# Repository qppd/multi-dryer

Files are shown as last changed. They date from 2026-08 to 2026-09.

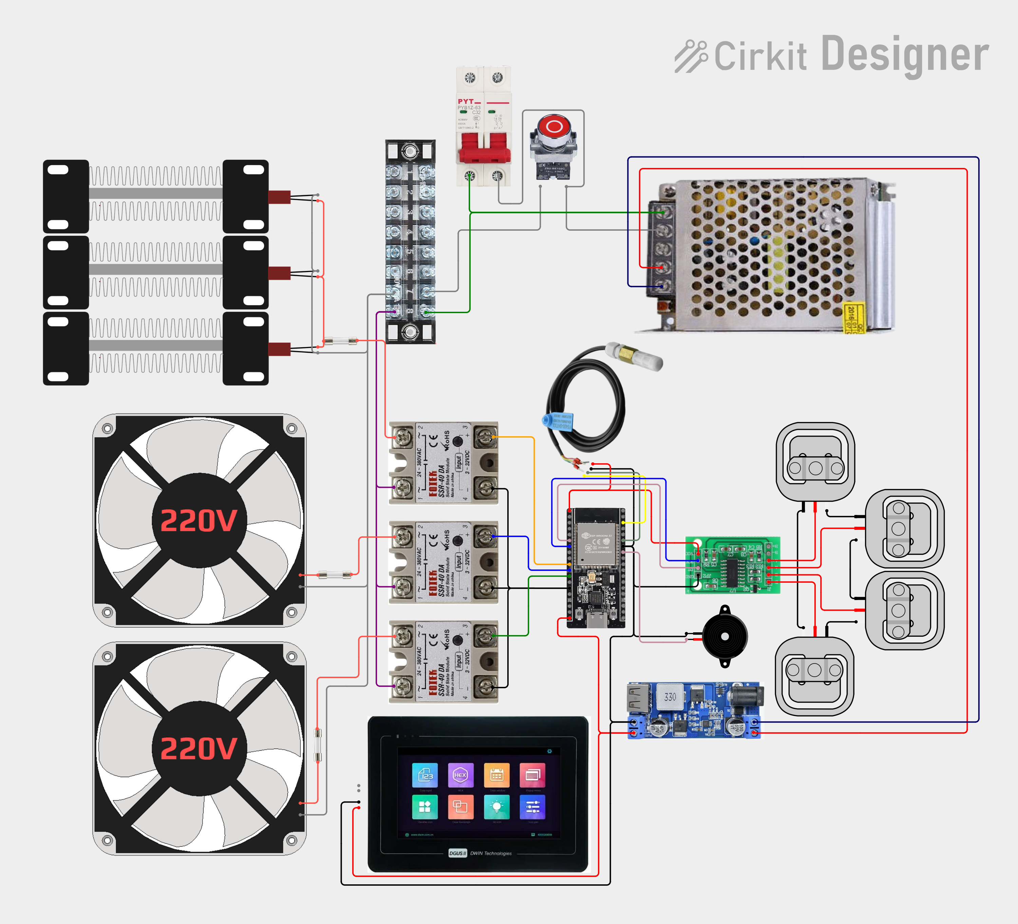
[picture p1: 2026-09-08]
docs/schematic/circuit_image.png

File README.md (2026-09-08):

# Multi Dryer







Smart food dehydration system built on a pair of ESP32 boards: a **controller** that runs the drying process (PTC heater, fans, load cell, temperature sensing) and a **touchscreen HMI** that provides the user interface. The two halves communicate **wirelessly over ESP-NOW** — no wiring between boards.

## Features

- **PID temperature control** — PTC heater regulated from SHT31 feedback (PD tuning, 0–5000 output, heat-vs-vent SSR strategy). Safety guard: the heater is forced OFF and the unit vents if the sensor feedback is lost.
- **Water-loss tracking** — load cell (HX711) measures the product weight; water loss is computed as % of the initial weight, with a configurable auto-complete target.
- **Drying state machine** — `IDLE → DRYING ⇄ PAUSED → COMPLETE`, with pause-aware runtime accounting and a rate-based *estimated drying time* (EDT).
- **Session persistence (NVS)** — interrupted drying sessions survive reboot/power-cycle: initial weight + HX711 zero reference, elapsed runtime, and targets are restored automatically (DRYING re-enables the PID). The last setpoint and water-loss target persist even when idle.
- **Full HMI control** — LVGL v8 touchscreen UI: dashboard, control, manual operation, analytics, diagnostics screens + completion alerts. Start / stop / pause / resume, **user-managed drying presets** (name + temperature + water-loss target, add/delete, saved in HMI NVS), live weight, water loss, runtime and EDT.
- **Manual overrides** — heater / inlet fan / exhaust toggles; any manual command ends an active session first so manual and automatic control never fight.
- **Boot- and WiFi-safe pin map** — no strapping, flash, or ADC2 pins used; all SSR outputs forced OFF at power-on (fail-safe).

## Repository Structure

```
multi-dryer/
├── src/
│   ├── MultiDryerController/   # ESP32 38-pin controller firmware (Arduino .ino + headers)
│   │   ├── MultiDryerController.ino   # entry point: sensors → PID → state machine → ESP-NOW
│   │   ├── PINS_CONFIG.h              # centralized, boot/WiFi-safe pin assignments
│   │   ├── SHT31_CONFIG.h             # SHT31 temp/humidity driver (I2C, non-blocking, CRC-8)
│   │   ├── LOADCELL_CONFIG.h          # HX711 load cell driver (kg, TARE/CALIBRATE, NVS factor)
│   │   ├── PID_CONFIG.h               # PID temperature control (PID_v1) + SHT31 vent guard
│   │   ├── DRYER_STATE.h              # state machine, water-loss math, NVS session persistence
│   │   ├── espnow_link.h              # ESP-NOW transport (1 Hz status, command ring buffer)
│   │   └── espnow_protocol.h          # shared packet protocol (byte-identical in both halves)
│   └── MultiDryerHMI/          # ESP32-S3 touchscreen HMI firmware (LVGL v8)
│       ├── MultiDryerHMI.ino          # entry point
│       ├── *_screen.cpp/.h            # boot, dashboard, control, manual operation,
│       │                              # analytics, diagnostics + alert popup
│       ├── serial_protocol.cpp/.h     # ESP-NOW transport to the controller
│       ├── dryer_data.h               # data model bridged from status packets
│       ├── lvgl_v8_port.* / ui_theme.h / ui_styles.* / screen_manager.*
│       ├── ui_optimistic_state.*      # instant UI feedback, corrected by 1 Hz status
│       └── esp_panel_board_custom_conf.h  # Waveshare Touch-LCD-7 board config (verify!)
└── docs/
    ├── README.md                      # documentation index & roadmap
    ├── api/espnow-protocol.md         # ESP-NOW protocol/API reference
    ├── stacks/tech-stack.md           # hardware + firmware + library stack
    ├── guides/bring-up-checklist.md   # ordered boot/hardware verification
    ├── guides/calibration-guide.md    # TARE + CALIBRATE:<kg>, NVS persistence
    ├── guides/troubleshooting.md      # pairing, vent guard, NVS issues
    ├── guides/bom.md                  # parts list with specs & quantities
    ├── guides/test-plan.md            # unit tests + HMI screen checks
    ├── schematic/hardware-wiring.md   # written pin-by-pin wiring plan
    ├── schematic/wiring-diagram.md    # Fritzing schematic (primary) + Cirkit Designer link
    ├── schematic/multidryer.fzz       # editable Fritzing schematic source (3-SSR build)
    ├── schematic/multidryer_schematic.png  # exported schematic view (PNG)
    └── diagrams/                      # block diagram + flow charts (Mermaid)
```

## Documentation

- [docs/README.md](docs/README.md) — index & required-docs roadmap
- [ESP-NOW protocol / API](docs/api/espnow-protocol.md) — packets, commands, states, pairing
- [Technology stack](docs/stacks/tech-stack.md) — hardware, firmware, libraries, tools
- [Wiring diagram & schematic](docs/schematic/wiring-diagram.md) — Fritzing schematic (primary) + interactive Cirkit Designer link
- [Hardware wiring plan](docs/schematic/hardware-wiring.md) — written pin-by-pin reference
- [Bring-up checklist](docs/guides/bring-up-checklist.md) — ordered boot/hardware verification
- [Calibration guide](docs/guides/calibration-guide.md) — TARE + CALIBRATE:<kg> procedure, NVS persistence
- [Troubleshooting guide](docs/guides/troubleshooting.md) — pairing, no-status-packet, sensor-fail vent behavior
- [BOM / procurement](docs/guides/bom.md) — full parts list with specs, quantities, and sourcing notes
- [Test plan](docs/guides/test-plan.md) — unit tests for protocol/state machine + HMI screen checks
- [System architecture](docs/system-architecture.md) — modules, data flow, design decisions
- [Block diagram](docs/diagrams/block-diagram.md) / [Flow charts](docs/diagrams/flow-chart.md) — Mermaid diagrams
- [Safety & thermal design](docs/guides/safety-and-thermal.md) — SSR strategy, fuses, thermal cutoff, vent guard
- [HMI user guide](docs/guides/hmi-user-guide.md) — screens, buttons, first-use workflow
- [UI screenshots](docs/ui/) — PNG previews of the real HMI screens (rendered with a headless LVGL tool kept out of the repo)

## Hardware

| Part | Spec / Use |
|---|---|
| ESP32 38-pin DevKitC (WROOM-32) | Main controller |
| ESP32-S3 + 7″ touch display (Waveshare Touch-LCD-7) | HMI (LVGL UI) |
| PTC heater 1500 W + 220 V fans ×2 (inlet, exhaust) | Drying loads, switched by SSRs |
| SSR-40DA modules ×3, 40 A (3–32 VDC input) | AC load switching (firmware-enforced fail-safe) |
| HX711 + 4× 50 kg load cells (summed bridge) | Weight / water-loss measurement |
| SHT31 | Temperature & humidity (PID feedback) |
| 220 VAC → 12 V 5 A PSU + 12 V → 5 V 3 A buck | Low-voltage supply |

### Controller Pin Map (summary)

| Function | GPIO |
|---|---|
| SSR1 — PTC heater | 26 |
| SSR3 — inlet fan | 27 |
| SSR4 — exhaust fan | 13 |
| HX711 DOUT / SCK | 35 / 32 |
| SHT31 SDA / SCL | 21 / 22 |

Full wiring plan: [`docs/schematic/hardware-wiring.md`](docs/schematic/hardware-wiring.md), the Fritzing schematic ([`multidryer.fzz`](docs/schematic/multidryer.fzz) — view: [`multidryer_schematic.png`](docs/schematic/multidryer_schematic.png)), and the interactive [Cirkit Designer schematic](https://app.cirkitdesigner.com/project/9d03db5a-37c8-4f46-ac3f-7d5821ce26ce).

## Getting Started

### Prerequisites

**Controller** (`src/MultiDryerController`)
- Arduino IDE or PlatformIO with **ESP32 Arduino core**
- Libraries: [`br3ttb/PID_v1`](https://github.com/br3ttb/Arduino-PID-Library), [`bogde/HX711`](https://github.com/bogde/HX711) (`Preferences` is built-in)

**HMI** (`src/MultiDryerHMI`)
- **LVGL 8.x** (enable fonts *Montserrat 14/16/20/24/30/36/48* and widgets *meter/chart/bar/slider/switch/tabview/checkbox/spinner/keyboard/textarea* in `lv_conf.h`)
- **ESP32_Display_Panel** library (`esp_display_panel.hpp`)
- ⚠️ `esp_panel_board_custom_conf.h` is configured for the **Waveshare ESP32-S3-Touch-LCD-7** — verify it matches your display/touch hardware, or init will fail silently.

### Flashing

1. Open the sketch folders (`src/MultiDryerController` / `src/MultiDryerHMI`) in the Arduino IDE, select the correct board, and upload.
2. **Pair the boards** (one-time, both default to channel 1):
   1. Boot the controller → note its MAC from the serial monitor.
   2. Paste it into `CONTROLLER_PEER_MAC` in `src/MultiDryerHMI/serial_protocol.cpp`.
   3. Boot the HMI → note its MAC.
   4. Paste it into `HMI_PEER_MAC` in `src/MultiDryerController/espnow_link.h`, re-flash the controller.
3. Open the serial monitors — status packets should flow at 1 Hz once paired.

## How It Works

1. The **controller** samples the SHT31 and load cell, runs PID temperature control on the PTC heater, and tracks the drying state machine with water-loss math.
2. Every second it broadcasts an **ESP-NOW status packet** (state, temp/humidity, weight, water loss, setpoint, PID output, runtime, EDT) to the HMI.
3. The **HMI** renders the dashboard and relays user commands (start/stop/pause/resume, setpoint, water-loss target, manual overrides, tare/calibrate) back over ESP-NOW. Commands are handled through an 8-slot ring buffer, so bursts are never dropped.
4. The drying session auto-completes when the water-loss target is reached — and survives reboots via NVS.

> The shared protocol (`espnow_protocol.h`) is **byte-identical** in both firmware folders — keep the two copies in sync when changing it.

## Author

**Sajed Lopez Mendoza** — *Building intelligent solutions* 🚀

- GitHub: [@qppd](https://github.com/qppd)
- LinkedIn: [sajed-mendoza](https://www.linkedin.com/in/sajed-mendoza)

## License

Distributed under the [MIT License](LICENSE).

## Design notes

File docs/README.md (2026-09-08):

# Multi Dryer — Documentation

Central index of all project documentation.

## Existing Docs

| Doc | Path | Status |
|---|---|---|
| Wiring diagram & schematic | [`schematic/wiring-diagram.md`](schematic/wiring-diagram.md) | ✅ Fritzing schematic current (3-SSR) — Cirkit link stale (old 4-SSR) |
| Hardware wiring plan (written) | [`schematic/hardware-wiring.md`](schematic/hardware-wiring.md) | ✅ complete |
| ESP-NOW protocol / API | [`api/espnow-protocol.md`](api/espnow-protocol.md) | ✅ complete |
| Technology stack | [`stacks/tech-stack.md`](stacks/tech-stack.md) | ✅ complete |
| Bring-up / boot checklist | [`guides/bring-up-checklist.md`](guides/bring-up-checklist.md) | ✅ complete |
| Calibration guide | [`guides/calibration-guide.md`](guides/calibration-guide.md) | ✅ complete |
| Troubleshooting guide | [`guides/troubleshooting.md`](guides/troubleshooting.md) | ✅ complete |
| System architecture | [`system-architecture.md`](system-architecture.md) | ✅ complete |
| Block diagram | [`diagrams/block-diagram.md`](diagrams/block-diagram.md) | ✅ complete |
| Flow charts | [`diagrams/flow-chart.md`](diagrams/flow-chart.md) | ✅ complete |
| Safety & thermal design | [`guides/safety-and-thermal.md`](guides/safety-and-thermal.md) | ✅ complete |
| HMI user guide | [`guides/hmi-user-guide.md`](guides/hmi-user-guide.md) | ✅ complete |

> Written pin-by-pin plan, planning notes, and reference projects live in
> `references/` (local, git-ignored) — notably
> `references/plans/hardware-wiring.md` and `references/plans/multi-dryer-planning.md`.

## Required Docs — Roadmap

Docs that should exist before / during hardware bring-up, in priority order:

| # | Doc | Why it's required | Status |
|---|---|---|---|
| 1 | **Hardware wiring plan (written)** | Pin-by-pin reference for assembly & debugging | ✅ [`schematic/hardware-wiring.md`](schematic/hardware-wiring.md) |
| 2 | **Bring-up / boot checklist** | Ordered tests (boot, fail-safe, flash, WiFi, load cell, outputs, thermal) | ✅ [`guides/bring-up-checklist.md`](guides/bring-up-checklist.md) |
| 3 | **Calibration guide** | TARE + two-point `CALIBRATE:<kg>` procedure and how the factor/session offset persist in NVS | ✅ [`guides/calibration-guide.md`](guides/calibration-guide.md) |
| 4 | **Architecture overview** | Module diagram & data flow (sensors → PID → state machine → ESP-NOW → HMI) for onboarding | ✅ [`system-architecture.md`](system-architecture.md) + [`diagrams/`](diagrams/) |
| 5 | **HMI user guide** | What each screen does, button semantics (start/pause/resume/stop, presets, manual mode) | ✅ [`guides/hmi-user-guide.md`](guides/hmi-user-guide.md) |
| 6 | **Troubleshooting guide** | MAC pairing, no-status-packet, sensor-fail vent behavior, NVS session resurrection | ✅ [`guides/troubleshooting.md`](guides/troubleshooting.md) |
| 7 | **Safety & thermal design** | SSR strategy, fuses, thermal cutoff, SHT31 vent guard, live-wiring rules | ✅ [`guides/safety-and-thermal.md`](guides/safety-and-thermal.md) |
| 8 | **BOM / procurement** | Parts list with specs & quantities for ordering | ✅ [`guides/bom.md`](guides/bom.md) |
| 9 | **Test plan** | Unit/bench tests for the state machine & protocol helpers, HMI screen checks | ✅ [`guides/test-plan.md`](guides/test-plan.md) |

## Conventions

- Keep protocol docs in sync with `espnow_protocol.h` (the header is the source of truth).
- Keep the shared header **byte-identical** in both firmware folders.
- Diagrams go in `docs/diagrams/`, schematics in `docs/schematic/`.

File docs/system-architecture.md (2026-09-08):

# System Architecture

High-level architecture of the Multi Dryer: two ESP32 boards, one shared
wireless protocol, and the module/data-flow design of each firmware.

> Diagrams: [`diagrams/block-diagram.md`](diagrams/block-diagram.md) ·
> [`diagrams/flow-chart.md`](diagrams/flow-chart.md) ·
> Protocol: [`api/espnow-protocol.md`](api/espnow-protocol.md) ·
> Stack: [`stacks/tech-stack.md`](stacks/tech-stack.md)

---

## 1. Overview

The system is a **two-board distributed design** with a strict separation of
concerns:

```
┌──────────────────────────────┐        ESP-NOW (wireless)        ┌──────────────────────────────┐
│        CONTROLLER            │ ◄══════════════════════════════► │             HMI              │
│   ESP32 38-pin (WROOM-32)    │    status 1 Hz / commands        │   ESP32-S3 + 7" touch LCD   │
│                              │                                  │                              │
│  sensing · control · safety  │                                  │  display · input · state     │
└──────────────────────────────┘                                  └──────────────────────────────┘
```

- The **controller** is the brain: it owns the sensors, the PID, the drying
  state machine, and the safety rules. It never needs the HMI to operate safely.
- The **HMI** is the face: LVGL touchscreen UI, optimistic button feedback, and
  display of controller data. It never makes control decisions.
- The only link is **ESP-NOW** — no UART, no I2C between boards. Each board's
  serial (UART0) is local flashing/debug only.

**Why two boards?** The 38-pin ESP32 runs the real-time control loop with clean
GPIOs for the SSRs and sensors; the ESP32-S3 runs the display without sharing
the controller's I/O. ESP-NOW keeps them physically independent (no wiring, no
ground loops in the mains enclosure).

---

## 2. Controller Architecture

Modules in `src/MultiDryerController/`, roughly in init order:

| Module | Responsibility |
|---|---|
| `MultiDryerController.ino` | Entry point: init sequence (pins → load cell → SHT31 → PID → drying → ESP-NOW) and the main loop |
| `PINS_CONFIG.h` | Boot/WiFi-safe pin assignments (single source of truth) |
| `SHT31_CONFIG.h` | Non-blocking SHT31 driver (I2C, CRC-8) → `getTemperature()` / `getHumidity()` |
| `LOADCELL_CONFIG.h` | HX711 driver: kg reads, TARE/CALIBRATE, factor in NVS |
| `PID_CONFIG.h` | PID_v1 temperature control + **vent safety guard** |
| `DRYER_STATE.h` | State machine, water-loss math, runtime/EDT, NVS session & config persistence |
| `espnow_link.h` | ESP-NOW: 1 Hz status broadcast, 8-slot command ring buffer |
| `espnow_protocol.h` | Shared packet protocol (byte-identical copy) |

### 2.1 Data flow (per loop iteration)

```
SHT31 ──► temperature/humidity ─┐
                                ├─► PID (PID_CONFIG) ─► SSRs (heat/vent)
HX711 ──► weight (1 Hz cache) ─┤        ▲ setpoint
                                └─► DRYER_STATE (state machine, water loss)
                                        │
espnow_link ◄── status packet (1 Hz) ───┘   commands ──► state machine / PID / manual
```

### 2.2 Safety architecture

1. **Boot fail-safe** — firmware forces all SSR pins LOW as the first step
   of `setup()`: nothing energizes during boot.
2. **Sensor-fail vent guard** — if `sht31OK` is false, `pidCOMPUTE()` forces
   heater + inlet fan OFF and vents (exhaust fan on): a dead sensor can
   never cause full-power heating.
3. **State-machine/manual arbitration** — any manual command ends an active
   session first, so PID and manual control never fight.
4. **TARE/CALIBRATE gate** — calibration is blocked unless IDLE, so a boot-time
   TARE can't destroy a restored session's zero reference.
5. **Hardware thermal cutoff** — thermal fuse/limit switch in series with the
   PTC heater branch (outside firmware).

---

## 3. HMI Architecture

Modules in `src/MultiDryerHMI/`:

| Module | Responsibility |
|---|---|
| `MultiDryerHMI.ino` | Entry point |
| `serial_protocol.*` | ESP-NOW transport: senders + `applyStatusPacket` (packet → `dryerData`) |
| `dryer_data.h` | Data model — the single source the screens read |
| `screen_manager.*` | Screen navigation |
| `boot_screen` / `dashboard` / `control` / `manual_operation` / `analytics` / `diagnostics` / `alert_popup` | LVGL screens |
| `ui_optimistic_state.*` | Instant UI feedback on button press, corrected by the next 1 Hz status |
| `lvgl_v8_port.*`, `ui_theme.h`, `ui_styles.*` | LVGL port, theme, styles |
| `esp_panel_board_custom_conf.h` | Display/touch board config (Waveshare-7″) |

### 3.1 UI data flow

```
ESP-NOW status ──► applyStatusPacket ──► dryerData ──► screens (2 s UI refresh)
ESP-NOW command ◄── button callbacks ◄── optimistic state ── touch input
```

---

## 4. Communication Architecture

- **Transport:** ESP-NOW over Wi-Fi STA, channel 1, no network connection.
- **Packets:** packed binary structs + XOR checksum (see `espnow_protocol.h`).
  - `EspNowStatusPacket` (38 B) — controller → HMI, 1 Hz.
  - `EspNowCmdPacket` (7 B) — HMI → controller, on demand.
- **Reliability:** status is periodic (a missed packet self-heals); commands are
  queued in an 8-slot ring buffer so bursts are never dropped during the
  ~300 ms HX711 read window. ESP-NOW ACK tracks `hmiReachable`.
- **Authoritative data:** runtime, EDT, water loss, and weight always come from
  the controller — the HMI never recomputes them.

---

## 5. Persistence Architecture (NVS)

| Namespace | Keys | Contents | Written by |
|---|---|---|---|
| `loadcell` | `factor` | Calibration factor (counts/kg) | `CALIBRATE:<kg>` |
| `drying` | `magic`, `state`, `initW`, `runMs`, `wlTgt`, `setpt`, `hxoff` | Active session: state, initial weight, elapsed runtime, water-loss target, setpoint, **HX711 raw offset** | session transitions + every 30 s while drying |
| `drying` | `magic`, `wlTgt`, `setpt` | Idle config (survives reboot with no session) | `SET_TEMPERATURE` / `SET_WATER_LOSS` |

Restore rules: valid `magic` + non-IDLE `state` → resume session (re-apply
offset, PID back on if DRYING). Config keys restore in every boot. Session
completion/stop clears the state marker only — config keys are preserved.

---

## 6. Key Design Decisions

| Decision | Rationale |
|---|---|
| ESP-NOW instead of wires | No inter-board wiring, no ground loops; same transport as the HMI reference baseline |
| Controller owns all safety | The dryer remains safe even if the HMI is dead or absent |
| 1 Hz weight cache in the state machine | Single read source → status packet and water-loss math always agree |
| NVS offset saved with the session | Survives full power cycles where HX711 offset drifts — no re-tare |
| Optimistic HMI UI | Feels instant; the 1 Hz status packet is the correction source |
| Boot-safe pin map | No strapping/flash/ADC2 pins → flashing and WiFi always work with peripherals attached |

## 7. References

- Wiring: [`schematic/hardware-wiring.md`](schematic/hardware-wiring.md)
- Protocol: [`api/espnow-protocol.md`](api/espnow-protocol.md)
- Stack: [`stacks/tech-stack.md`](stacks/tech-stack.md)
- Bring-up: [`guides/bring-up-checklist.md`](guides/bring-up-checklist.md)
- Troubleshooting: [`guides/troubleshooting.md`](guides/troubleshooting.md)

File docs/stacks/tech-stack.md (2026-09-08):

# Technology Stack

Everything used to build the Multi Dryer system — hardware, firmware, libraries,
and tooling.

---

## 1. Hardware Stack

| Layer | Item | Role |
|---|---|---|
| Controller MCU | **ESP32 38-pin DevKitC** (WROOM-32 module) | Runs the drying process: sensors, PID, state machine, ESP-NOW |
| HMI MCU | **ESP32-S3** (Waveshare ESP32-S3-Touch-LCD-7) | 800×480 RGB LCD + GT911 capacitive touch, runs the LVGL UI |
| Temperature/humidity | **SHT31** (I2C, addr 0x44) | Chamber feedback for PID + humidity reporting |
| Weight | **HX711** 24-bit ADC + 4× 50 kg load cells (summed full-bridge, 200 kg) | Product weight → water-loss % |
| Heating | **PTC heater** (1500 W) | Drying heat, switched by SSR1 |
| Airflow | Inlet fan + exhaust fan (220 V AC) | Circulation & moisture venting, SSRs 3–4 |
| Power switching | **3× SSR-40DA (40 A)** (3–32 VDC input / 220 VAC output) | Opto-isolated mains switching; firmware-enforced fail-safe OFF at boot |
| Power | 220 VAC → 12 V 5 A PSU + 12 V → 5 V 3 A buck converter | 5 V rail feeds ESP32; onboard regulator makes 3.3 V |
| Protection | Fuses per AC branch + thermal cutoff on heater branch | Safety |

Pin allocation: `src/MultiDryerController/PINS_CONFIG.h` · wiring plan:
`docs/schematic/wiring-diagram.md`

---

## 2. Firmware Stack

### Controller — `src/MultiDryerController` (Arduino sketch + headers)

| Module | Responsibility |
|---|---|
| `MultiDryerController.ino` | Entry point: init order (pins → load cell → SHT31 → PID → drying → ESP-NOW), main loop |
| `PINS_CONFIG.h` | Boot/WiFi-safe pin assignments |
| `SHT31_CONFIG.h` | Non-blocking SHT31 driver, hardware I2C, CRC-8 |
| `LOADCELL_CONFIG.h` | HX711 driver: kg readings, TARE/CALIBRATE, calibration factor in NVS |
| `PID_CONFIG.h` | PID temperature control (PID_v1) + SHT31 vent safety guard |
| `DRYER_STATE.h` | State machine, water-loss math, runtime/EDT, NVS session + config persistence |
| `espnow_link.h` | ESP-NOW transport: 1 Hz status, 8-slot command ring buffer |
| `espnow_protocol.h` | Shared protocol (byte-identical copy) |

### HMI — `src/MultiDryerHMI` (Arduino sketch, LVGL v8)

| Module | Responsibility |
|---|---|
| `MultiDryerHMI.ino` | Entry point |
| `boot_screen` / `dashboard_screen` / `control_screen` / `manual_operation_screen` / `analytics_screen` / `diagnostics_screen` / `alert_popup` | UI screens |
| `serial_protocol.*` | ESP-NOW transport to the controller |
| `dryer_data.h` | Data model bridged from status packets |
| `ui_optimistic_state.*` | Instant button feedback, corrected by 1 Hz status |
| `lvgl_v8_port.*`, `ui_theme.h`, `ui_styles.*`, `screen_manager.*` | LVGL port, theme, screen navigation |
| `esp_panel_board_custom_conf.h` | Board config — **Waveshare-7″-specific, verify against real hardware** |

---

## 3. Libraries

| Library | Used by | Version / notes |
|---|---|---|
| **ESP32 Arduino core** | both | `WiFi`, `Preferences`, `Wire` (built-in) |
| **PID_v1** (`br3ttb/Arduino-PID-Library`) | controller | PD tuning: KP 4.0, KI 0.0, KD 22.0 |
| **HX711** (`bogde/HX711`) | controller | Reads + tare + offset management |
| **LVGL 8.x** | HMI | Fonts Montserrat 14/16/20/24/30/36/48; widgets meter/chart/bar/slider/switch/tabview/checkbox/spinner |
| **ESP32_Display_Panel** (`esp_display_panel.hpp`) | HMI | RGB LCD + GT911 touch init (Waveshare board config) |

---

## 4. Communication

- **Transport:** ESP-NOW (Wi-Fi STA mode, channel 1) — wireless, no wiring between boards.
- **Protocol:** packed binary structs + XOR checksum, defined in `espnow_protocol.h`
  (byte-identical on both sides). Full reference: `docs/api/espnow-protocol.md`.
- **Cadence:** status 1 Hz; commands on-demand with an 8-slot receive queue.
- **Persistence:** NVS (`Preferences`, namespace `drying`) for calibration factor,
  session state, and last setpoint/water-loss target.

---

## 5. Tooling

| Tool | Use |
|---|---|
| Arduino IDE (or PlatformIO) | Build & flash both sketches |
| esptool / Arduino uploader | Flashing via UART0 (GPIO 1/3) |
| Serial monitor | MAC pairing, debug prints |
| **Fritzing** (0.9.3b) | Canonical editable schematic — `docs/schematic/multidryer.fzz` (see [`wiring-diagram.md`](../schematic/wiring-diagram.md)) |
| Cirkit Designer | Legacy interactive wiring schematic (link in `docs/schematic/wiring-diagram.md`) |
| GitHub (qppd/multi-dryer) | Version control, docs, issues |
| PID_v1 / HX711 / LVGL docs | Library API references |

---

## 6. Design Principles (why the stack is safe)

1. **Boot-safe pins** — no strapping (0/2/4/5/12/15), flash (6–11), or boot-PWM (14) pins.
2. **WiFi-safe pins** — no analog reads on ADC2 (unusable with WiFi active); HX711 path is fully digital.
3. **Fail-safe outputs** — firmware forces all SSR pins LOW first thing in `setup()`.
4. **Sensor-fail safety** — SHT31 loss forces the heater OFF and vents instead.
5. **Single transport** — ESP-NOW only between boards; UART0 is local debug only.

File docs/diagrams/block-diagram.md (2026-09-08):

# Block Diagram

System block diagram (Mermaid — renders on GitHub).

```mermaid
flowchart TB
    subgraph AC["220 VAC Mains"]
        M[AC-L / AC-N]
    end

    subgraph PWR["Power"]
        PSU["220 V → 12 V 5 A PSU"]
        BUCK["12 V → 5 V 3 A buck"]
        F1["Fuse 10A"] & F2["Fuse 2A"] & F3["Fuse 2A"]
        TCO["Thermal cutoff<br/>(heater branch)"]
    end

    subgraph CTRL["CONTROLLER — ESP32 38-pin (WROOM-32)"]
        direction TB
        ESP["ESP32 SoC"]
        subgraph MOD["Firmware modules"]
            SHT["SHT31_CONFIG.h"]
            LC["LOADCELL_CONFIG.h"]
            PID["PID_CONFIG.h<br/>+ vent guard"]
            ST["DRYER_STATE.h<br/>state machine / NVS"]
            LNK["espnow_link.h"]
            SHARED["espnow_protocol.h<br/>(shared, byte-identical)"]
        end
    end

    subgraph SENS["Sensors"]
        S31["SHT31<br/>temp/humidity<br/>(I2C 21/22)"]
        HX["HX711<br/>(DOUT 35 / SCK 32)"]
        CELL["Load cells 4× 50 kg<br/>(summed bridge)"]
    end

    subgraph SSR["SSR Bank — 3× SSR-40DA 40 A (3–32 VDC in)"]
        R1["SSR1 — PTC heater<br/>(GPIO 26)"]
        R3["SSR3 — inlet fan<br/>(GPIO 27)"]
        R4["SSR4 — exhaust fan<br/>(GPIO 13)"]
    end

    subgraph LOADS["AC Loads"]
        HTR["PTC heater 1500 W"]
        IF["Inlet fan"]
        EF["Exhaust fan"]
    end

    subgraph HMI["HMI — ESP32-S3 + 7″ touch LCD"]
        HMI_ESP["ESP32-S3"]
        DSP["RGB LCD 800×480<br/>(ST7262)"]
        TCH["GT911 touch"]
        subgraph HMI_MOD["Firmware modules"]
            PROTO["serial_protocol.*<br/>(ESP-NOW)"]
            PRESETS["drying_presets.*<br/>(NVS presets)"]
            OPT["ui_optimistic_state.*<br/>(instant feedback)"]
            SM["screen_manager.*<br/>6 screens + alerts"]
        end
        LVGL["LVGL 8.x UI"]
    end

    M --> PSU --> BUCK --> ESP
    ESP --> S31 & HX
    CELL --> HX
    S31 -.->|I2C| SHT
    HX -.->|kg| LC
    M --> F1 --> TCO --> R1
    M --> F2 --> R3
    M --> F3 --> R4
    R1 --> HTR
    R3 --> IF
    R4 --> EF

    SHT --> PID
    LC --> ST
    PID --> ST
    ST --> LNK
    LNK -. "ESP-NOW 1 Hz status" .-> PROTO
    PROTO -. "commands" .-> LNK
    PRESETS --> LVGL
    OPT --> LVGL
    SM --> LVGL
    PROTO --> LVGL
    LVGL --> DSP
    TCH --> LVGL
    HMI_ESP --> DSP & TCH
```

## Legend

| Block | Notes |
|---|---|
| Mains | 220 VAC, fused per branch (10/2/2 A) |
| PSU | 220 V → 12 V 5 A PSU + 12 V → 5 V 3 A buck (5 V rail → ESP32; onboard regulator makes 3.3 V) |
| Thermal cutoff | Mandatory, in series with the PTC heater branch |
| SSR bank | 3× SSR-40DA 40 A (SSR1 heater, SSR3 inlet, SSR4 exhaust); opto-isolated 3–32 VDC input; firmware forces inputs LOW at boot |
| ESP-NOW | Wireless, channel 1, packed binary packets — `espnow_protocol.h` is byte-identical on both boards (see `api/espnow-protocol.md`) |
| Sensors | SHT31 on I2C; HX711 fully digital (no ADC2 dependence) |
| HMI | ESP32-S3 + 7″ RGB LCD (ST7262) + GT911 touch; LVGL 8.x; 6 screens (boot, dashboard, control, analytics, diagnostics, HOW TO USE); drying presets in NVS; optimistic button feedback; alerts |

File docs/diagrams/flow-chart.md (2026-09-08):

# Flow Charts

Control-flow diagrams (Mermaid — renders on GitHub).

---

## 1. Controller Boot Flow

```mermaid
flowchart TD
    A["Power on / reset"] --> B["setup()<br/>1. SSR pins forced LOW (fail-safe)"]
    B --> C["2. initLoadCell() — HX711<br/>restore calibration factor from NVS"]
    C --> D["3. initSHT31() — I2C<br/>temp/humidity, presence check"]
    D --> E["4. initPID() — MANUAL (off)"]
    E --> F["5. initDrying() — restore<br/>session + config from NVS"]
    F --> G["6. initEspNow() — pair peer<br/>+ register callbacks"]
    G --> H{"Saved session?"}
    H -->|"PAUSED"| I["Stay PAUSED — all outputs off"]
    H -->|"DRYING"| J["Resume DRYING — PID back on,<br/>HX711 offset re-applied"]
    H -->|"none / COMPLETE"| K["IDLE — config restored<br/>(setpoint + water-loss target)"]
    I --> L["loop()"]
    J --> L
    K --> L
```

---

## 2. Main Loop (every iteration)

```mermaid
flowchart TD
    A["loop()"] --> B["updateSHT31()<br/>non-blocking sensor read<br/>state machine"]
    B --> C["pidCOMPUTE()<br/>heat or vent — SHT31 vent guard<br/>(PID_v1 throttles to 2 s)"]
    C --> D["updateDrying()<br/>1 Hz tick — weight cache, water loss,<br/>EDT, auto-complete, session save"]
    D --> E["espnowUpdate()<br/>dequeue 1 cmd + 1 Hz status"]
    E --> F["5 s debug status print"]
    F --> A
```

---

## 3. Drying State Machine

```mermaid
stateDiagram-v2
    [*] --> IDLE: boot — no saved session
    [*] --> DRYING: boot — saved DRYING<br/>(PID back on)
    [*] --> PAUSED: boot — saved PAUSED<br/>(all outputs off)
    IDLE --> DRYING: START_DRYING<br/>(capture initial weight, PID on)
    DRYING --> PAUSED: PAUSE_DRYING<br/>(all SSRs off, session saved)
    PAUSED --> DRYING: RESUME_DRYING<br/>(PID back on)
    DRYING --> COMPLETE: water loss ≥ target<br/>(auto — all SSRs off, session cleared)
    COMPLETE --> IDLE: STOP_DRYING
    COMPLETE --> DRYING: START_DRYING<br/>(fresh session)
    PAUSED --> IDLE: STOP_DRYING
    DRYING --> IDLE: STOP_DRYING / manual override
    IDLE --> IDLE: manual HEATER/FAN/EXHAUST
```

> **Boot-resume:** `initDrying()` restores a saved session from NVS — a DRYING
> session re-enables the PID; a PAUSED session stays off. Completed sessions
> clear the NVS marker, so a finished cycle always boots to IDLE.

---

## 4. PID + Sensor-Fail Decision

```mermaid
flowchart TD
    A["pidCOMPUTE()"] --> B{"PID mode == AUTOMATIC?"}
    B -->|"NO (MANUAL)"| Z["Return — outputs untouched"]
    B -->|"YES"| C{"SHT31 valid?"}
    C -->|"NO"| V["VENT SAFETY:<br/>heater OFF, inlet OFF<br/>exhaust fan ON"]
    C -->|"YES"| D["pid.Compute()"]
    D --> E{"PID_OUTPUT > 0?"}
    E -->|"YES"| H["HEAT:<br/>SSR1 PTC + SSR3 inlet ON<br/>SSR4 OFF"]
    E -->|"NO"| V2["VENT:<br/>SSR1 + SSR3 OFF<br/>SSR4 exhaust fan ON"]
    V --> Z
    H --> Z
    V2 --> Z
```

---

## 5. ESP-NOW Command Path (HMI → Controller)

```mermaid
sequenceDiagram
    participant UI as LVGL screen (HMI)
    participant H as serial_protocol (HMI)
    participant C as espnow_link (Controller)
    participant S as State machine / PID

    UI->>H: button callback
    H->>H: optimistic UI state (instant)
    H->>C: EspNowCmdPacket (7 B)
    C->>C: validate + enqueue (8-slot ring)
    C->>C: dequeue 1 per loop
    C->>S: handleCmd()
    S-->>C: effect (start/pause/…)
    C-->>H: status packet (1 Hz, corrects UI)
```

---

> Related: [`../system-architecture.md`](../system-architecture.md) ·
> [`api/espnow-protocol.md`](../api/espnow-protocol.md) ·
> [`guides/bring-up-checklist.md`](../guides/bring-up-checklist.md)

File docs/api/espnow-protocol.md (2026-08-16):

# ESP-NOW Protocol Reference (Controller ⇄ HMI)

The two firmware halves communicate **exclusively over ESP-NOW** — a wireless,
low-latency link built into the ESP32. There is **no wired connection** (no UART,
no I2C) between the controller and the HMI.

- **Shared header:** `espnow_protocol.h` — **byte-identical** in
  `src/MultiDryerController/` and `src/MultiDryerHMI/`. Keep both copies in sync
  when changing the protocol.
- **Wi-Fi channel:** `ESPNOW_WIFI_CHANNEL` = 1 on both sides.
- **Mode:** both boards run `WiFi.mode(WIFI_STA)` (no network connection needed).

---

## 1. Packet Framing

Both packets are packed C structs (little-endian, ESP32 Xtensa — binary-compatible
between boards). Every packet ends with a **checksum**: the XOR of all preceding
bytes. A receiver drops any packet whose type or checksum doesn't validate.

```
| packetType | payload ... | checksum |
```

| Packet | Direction | Size | ID |
|---|---|---|---|
| `EspNowStatusPacket` | Controller → HMI | **38 bytes** | `0x01` |
| `EspNowCmdPacket` | HMI → Controller | **7 bytes** | `0x02` |

---

## 2. EspNowStatusPacket — Controller → HMI (38 bytes)

Broadcast at **1 Hz** while the controller is running, and on demand after
`CMD_STATUS_REQUEST` / `CMD_SENSOR_TEST`. This is the HMI's only source of truth
for the machine state.

| Field | Type | Bytes | Description |
|---|---|---|---|
| `packetType` | uint8_t | 1 | `ESPNOW_PKT_STATUS` (0x01) |
| `state` | uint8_t | 1 | `DSTATE_*` — see [§4](#4-dryer-states) |
| `flags` | uint8_t | 1 | `FLAG_*` bitmask — see [§5](#5-status-flags) |
| `temperature` | float | 4 | Chamber temperature, °C (SHT31) |
| `humidity` | float | 4 | Humidity, % (SHT31) |
| `weight` | float | 4 | Current product weight, kg (HX711, 1 Hz cache) |
| `waterLoss` | float | 4 | Water lost so far, % of initial weight |
| `setpoint` | float | 4 | Target temperature, °C |
| `waterLossTarget` | float | 4 | Auto-complete target, % (0 = disabled) |
| `pidOutput` | float | 4 | PID output, 0–5000 |
| `runtimeSeconds` | uint16_t | 2 | Drying runtime (pauses excluded), s — wraps ~18 h |
| `estimatedEDT` | uint32_t | 4 | Estimated time to completion, s (0 = unknown) |
| `checksum` | uint8_t | 1 | XOR of bytes [0..36] |

> `runtimeSeconds` and `estimatedEDT` are authoritative from the controller's
> state machine (`DRYER_STATE.h`) — the HMI must display them as-is, not
> recompute from its own clock.

---

## 3. EspNowCmdPacket — HMI → Controller (7 bytes)

| Field | Type | Bytes | Description |
|---|---|---|---|
| `packetType` | uint8_t | 1 | `ESPNOW_PKT_CMD` (0x02) |
| `cmdType` | uint8_t | 1 | `CMD_*` — see [§3.1](#31-command-reference) |
| `value` | float | 4 | Optional parameter (0.0 when unused) |
| `checksum` | uint8_t | 1 | XOR of bytes [0..5] |

### 3.1 Command Reference

| ID | Command | Value | Effect on controller |
|---|---|---|---|
| 0x01 | `CMD_SET_TEMPERATURE` | target °C | Sets the PID setpoint; persists to NVS |
| 0x02 | `CMD_START_DRYING` | — | Starts a fresh drying session (captures initial weight, PID on) |
| 0x03 | `CMD_STOP_DRYING` | — | Ends the session (all SSRs off, session cleared) |
| 0x04 | `CMD_PAUSE_DRYING` | — | Pauses: all SSRs off, session saved (resumable) |
| 0x05 | `CMD_RESUME_DRYING` | — | Resumes a paused session (PID back on) |
| 0x10 | `CMD_HEATER_ON` | — | Manual: PTC heater + inlet fan on (ends any session first) |
| 0x11 | `CMD_HEATER_OFF` | — | Manual: stops session/all outputs |
| 0x12 | `CMD_FAN_ON` | — | Manual: inlet fan on (ends any session first) |
| 0x13 | `CMD_FAN_OFF` | — | Manual: stops session/all outputs |
| 0x14 | `CMD_EXHAUST_ON` | — | Manual: exhaust fan on (vents the chamber) |
| 0x15 | `CMD_EXHAUST_OFF` | — | Manual: stops session/all outputs |
| 0x20 | `CMD_PID_START` | — | Alias of `CMD_START_DRYING` (FishDryer baseline) |
| 0x21 | `CMD_PID_STOP` | — | Alias of `CMD_STOP_DRYING` |
| 0x22 | `CMD_SET_WATER_LOSS` | target % | Sets the auto-complete target; persists to NVS |
| 0x30 | `CMD_STATUS_REQUEST` | — | Forces an immediate status packet |
| 0x40 | `CMD_TARE_SCALE` | — | Tares the load cell (**blocked unless IDLE**) |
| 0x41 | `CMD_CALIBRATE_SCALE` | known weight kg | Two-point calibration (**blocked unless IDLE**) |
| 0x50 | `CMD_SENSOR_TEST` | — | Forces an immediate status packet (sensor check) |

> **TARE/CALIBRATE are gated to the IDLE state.** The HMI sends a TARE at every
> boot; if a session is active (or was restored from NVS), the TARE is ignored so
> it can't destroy the restored zero reference.

---

## 4. Dryer States

| Value | State | Meaning |
|---|---|---|
| 0 | `DSTATE_IDLE` | No session; manual mode available |
| 1 | `DSTATE_DRYING` | Active session; PID regulating the heater |
| 2 | `DSTATE_COMPLETE` | Target water loss reached; all outputs off |
| 3 | `DSTATE_PAUSED` | Session paused; all outputs off, resumable |

Transitions: `IDLE →START→ DRYING ⇄PAUSE/RESUME⇄ PAUSED`, `DRYING →COMPLETE` (auto
when the water-loss target is reached), any → `IDLE` via STOP.

---

## 5. Status Flags

Bitmask in `EspNowStatusPacket.flags` — reflects the **real SSR output state**.

| Bit | Flag | Set when |
|---|---|---|
| 0x01 | `FLAG_HEATER` | PTC heater SSR is energized |
| 0x02 | `FLAG_FAN` | Inlet fan SSR is energized |
| 0x04 | `FLAG_EXHAUST` | Exhaust SSR(s) energized |
| 0x08 | `FLAG_PID` | PID is in AUTOMATIC mode |
| 0x10 | `FLAG_SHT31` | SHT31 sensor reporting valid data |

---

## 6. Message Flow & Reliability

1. **Controller → HMI:** status packet every 1 s (`espnowUpdate()` → `sendStatusNow()`).
2. **HMI → Controller:** commands via `serial_protocol.cpp` senders; the controller
   queues them in an **8-slot ring buffer** (`cmdQueue*` in `espnow_link.h`) and
   drains one per loop — bursts (e.g. `SET_TEMPERATURE → SET_WATER_LOSS →
   START_DRYING`) are never dropped, even during the ~300 ms HX711 read window.
3. **Delivery:** ESP-NOW ACK updates the controller's `hmiReachable` flag; send
   failures are logged (`check CONTROLLER_PEER_MAC`).
4. **HMI UI:** buttons use optimistic state immediately, corrected by the next
   1 Hz status packet.

---

## 7. Pairing (one-time)

1. Boot the controller → note its MAC (`[ESP-NOW] Controller MAC: …`).
2. Paste it into `CONTROLLER_PEER_MAC` in `src/MultiDryerHMI/serial_protocol.cpp`.
3. Boot the HMI → note its MAC.
4. Paste it into `HMI_PEER_MAC` in `src/MultiDryerController/espnow_link.h`, re-flash.

No packets flow until both MACs are configured. Both must be on channel 1.

---

## 8. Extending the Protocol

1. Edit **both** copies of `espnow_protocol.h` identically (byte-identical code).
2. Add the command ID / field in the middle (not at the end) only if you also
   bump the checksum coverage — simplest is to append fields and keep the
   `checksum` as the last byte.
3. Add the handler in `espnow_link.h::handleCmd()` (controller) and the sender +
   `applyStatusPacket` mapping in the HMI (`serial_protocol.cpp`).
4. Version note: both structs are fixed-size; changing `sizeof` breaks older
   firmware — re-flash both boards together.

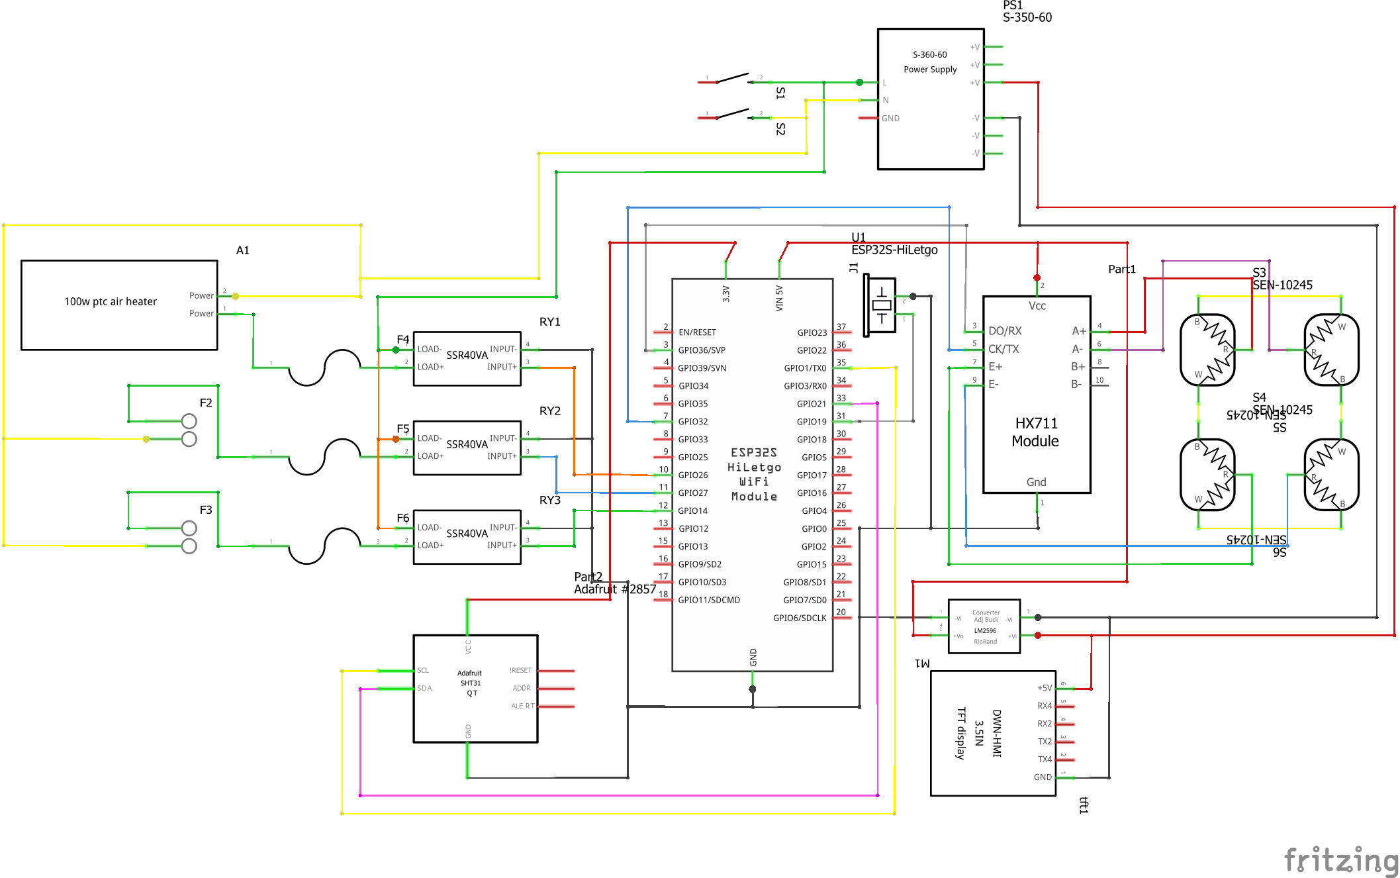
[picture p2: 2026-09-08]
docs/schematic/multidryer_schematic.png

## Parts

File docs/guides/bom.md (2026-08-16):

# Bill of Materials (BOM) — Multi Dryer

Parts list for ordering and assembly. Quantities are per **one** unit. Specs match
the wiring plan [`../schematic/hardware-wiring.md`](../schematic/hardware-wiring.md)
and the safety design [`safety-and-thermal.md`](safety-and-thermal.md).

> **Verify before ordering:** the controller board module type (WROOM vs WROVER,
> wiring plan §5.3), the HMI display board (must match
> `esp_panel_board_custom_conf.h` — currently **Waveshare ESP32-S3-Touch-LCD-7**),
> and the SSR input drive level (3–32 VDC input is required for direct 3.3 V drive).

---

## 1. Full BOM

| # | Qty | Item | Spec / Model | Notes |
|---|---|---|---|---|
| 1 | 1 | Controller board | **ESP32 38-pin DevKitC (WROOM-32)** | Verify module type — see §5.3 |
| 2 | 1 | HMI board | **ESP32-S3 + 7″ touch LCD (Waveshare ESP32-S3-Touch-LCD-7)** | 800×480 RGB + GT911; board config must match |
| 3 | 3 | Solid-state relay | **SSR-40DA, 40 A — 3–32 VDC input / 220 VAC output** | SSR1 = heater, SSR3 = inlet fan, SSR4 = exhaust fan (wiring §1) |
| 4 | 1 | Heater | **PTC heater, 1500 W** | Switched by SSR1 (safety §6) |
| 5 | 2 | Fans | **220 VAC axial fans** | Inlet (SSR3) + exhaust (SSR4) |
| 6 | 4 | Load cells | **50 kg each, 4-wire** (Red→E+, Black→E−, Green→A+, White→A−) | Summed full-bridge on one HX711 → 200 kg total (wiring §2.3) |
| 7 | 1 | HX711 breakout | 24-bit ADC (10 SPS default) | Powered from 3V3 |
| 8 | 1 | Temp/humidity sensor | **SHT31 breakout, I2C addr 0x44** | 0x45 if ADDR tied HIGH; temp feedback for PID |
| 9 | 1 | Mains PSU | **220 VAC → 12 V DC, 5 A (60 W)** | Mains-isolated 12 V rail |
| 10 | 1 | Buck converter | **12 V → 5 V DC, 3 A** | Feeds ESP32 5V pin; onboard regulator makes 3.3 V |
| 11 | 3 | Fuses + holders | **10 A (heater) / 2 A (inlet fan) / 2 A (exhaust fan)** | One per AC branch, ~1.5× steady-state current |
| 12 | 1 | Thermal cutoff | Thermal fuse or bimetallic limit switch, rated just above max chamber temp | **Mandatory** — in series with heater branch only |
| 13 | 1 | Decoupling cap | 100 nF ceramic (HX711 VCC–GND) | Optional but recommended (wiring §2.3) |
| 14 | — | Heatsinks | For all 3 SSRs | + airflow past the SSR bank |
| 15 | — | Wire, terminals, glands, enclosure | Proper gauge AC wire, cable glands / separate ducting | Keep AC ≥ 6 mm from signal wiring |
| 16 | *opt* | NTC thermistor | On a spare ADC1 pin (GPIO 34/36/39) | Future firmware over-temp cutoff (safety §6) |

---

## 2. What's deliberately NOT on this BOM

- **Resistors / pull-downs** — the SSR fail-safe is firmware-enforced (pins forced
  LOW at the top of `setup()`); no external divider or pull-down network is required.
- **RC snubbers** — not required; add only if motor noise causes false SSR switching
  in your install (treat as a debug fix, not a build part).
- **5 V level shifter / transistor drivers** — HX711 runs at 3V3 with direct logic
  levels; SSRs must be 3–32 VDC input types driven straight from 3.3 V GPIOs.
- **Separate switched exhaust outlet** — venting is done by the exhaust fan (SSR4)
  alone; there is no outlet SSR branch in this build (wiring §2.1).

---

## 3. Ordering Notes

- **Controller** — any 38-pin ESP32 DevKitC works, but confirm **WROOM-32 vs WROVER**
  (GPIO 16/17 differ). Buy 2 if you want a spare for bench experiments.
- **SSRs** — three identical **SSR-40DA 40 A** modules cover every branch (heater
  and both fans); the 40 A rating gives large headroom over the ~6.8 A heater load.
  Heatsinks come separately.
- **Load cells** — buy a **matched set of 4 × 50 kg** cells; wire all four in a
  summed full-bridge (all E+/E−/A+/A− paralleled) into the single HX711 channel →
  200 kg total capacity.
- **SHT31** — breakout modules usually include onboard I2C pull-ups; this build
  relies on the module's own pull-ups (none are added externally).
- **HMI** — the firmware board config is Waveshare-specific. If you use a different
  ESP32-S3 display, update `esp_panel_board_custom_conf.h` first.
- **Power** — 220 VAC → 12 V / 5 A PSU plus a 12 V → 5 V / 3 A buck converter.
  Check the buck's current rating: ESP32 + HX711 + SHT31 draw well under 3 A.
- **Local sourcing** (Philippines): Shopee / Lazada for DevKitC, HX711 + 4× 50 kg
  load-cell sets, SSR-40DA modules, and SHT31 breakouts; e-Gizmo / DIY Electronics
  (Manila) for 12 V PSUs, 12 V→5 V buck converters, fuses, heatsinks, and enclosure
  supplies. PTC heaters sized for food dryers are usually ordered online (1500 W
  chamber heater).
- **Fuses** — buy the rated cartridge/insert fuses plus holders; keep spares.

---

## 4. Related

- Wiring: [`../schematic/hardware-wiring.md`](../schematic/hardware-wiring.md) §2 & §6
- Safety & thermal: [`safety-and-thermal.md`](safety-and-thermal.md)
- Bring-up order: [`bring-up-checklist.md`](bring-up-checklist.md) — Phase 0 pre-flight

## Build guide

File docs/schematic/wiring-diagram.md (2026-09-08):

# Multi Dryer — Wiring Diagram

## Fritzing schematic (primary)

The canonical schematic is maintained in Fritzing:

- **Source (editable):** [`multidryer.fzz`](multidryer.fzz) — open in [Fritzing](https://fritzing.org) (made with 0.9.3b)
- **Exported view:** [`multidryer_schematic.png`](multidryer_schematic.png) — schematic-view render
- Reflects the **current 3-SSR build** (3× SSR-40DA, 1500 W PTC heater, 4× 50 kg load cells on one HX711, 220 VAC → 12 V PSU + LM2596 buck to 5 V, fused AC branches)

> The `.fzz` is the source of truth for the schematic. Re-export the PNG
> (`File → Export → PNG`) after every edit and commit both together.

## Interactive schematic (secondary)

Cirkit Designer project:

**https://app.cirkitdesigner.com/project/9d03db5a-37c8-4f46-ac3f-7d5821ce26ce**

> Requires a Cirkit Designer account/login to view.

> ⚠️ **Status:** the saved Cirkit project still shows the **old 4-SSR design**
> (4 SSRs, 5 V PSU, single load cell, exhaust outlet, fuses 10/5/2/2 A).
> It has been superseded by the Fritzing schematic above. The checklist
> below is kept for reference if the Cirkit project is ever refreshed.

---

## Cirkit update checklist — 3-SSR build

Edit the project in the Cirkit Designer editor, then save + re-share the link.

### Parts (swap these)

| # | In the project now | Change to | Qty |
|---|---|---|---|
| 1 | SSR modules ×4 (mixed 25/10 A) | **SSR-40DA, 40 A — 3–32 VDC input / 220 VAC output** | **3** |
| 2 | PTC heater 500–2000 W | **PTC heater, 1500 W** | 1 |
| 3 | Load cell ×1 (1–50 kg) | **Load cells ×4 (50 kg each)**, wired as a summed full-bridge (all E+/E−/A+/A− paralleled into the one HX711 channel) | **4** |
| 4 | 5 V isolated PSU | **220 VAC → 12 V / 5 A PSU** + **12 V → 5 V / 3 A buck converter** | 1 + 1 |
| 5 | Fuses 10 A / 5 A / 2 A / 2 A | **10 A (heater) / 2 A (inlet fan) / 2 A (exhaust fan)** — delete the 5 A outlet fuse | **3** |
| 6 | Exhaust outlet + its SSR | **Remove entirely** — venting is the exhaust fan (SSR4) | 0 |

### Connections (re-wire these)

1. **AC side** — remove the SSR2 branch (`F2 5A fuse → SSR2 → exhaust outlet`).
   Remaining branches, all returning to AC-N:
   ```
   AC-L ──┬─[F1 10A]──[Thermal cutoff]── SSR1 ── PTC Heater ──┐
          ├─[F2  2A]── SSR3 ── Inlet Fan ─────────────────────┤── AC-N
          └─[F3  2A]── SSR4 ── Exhaust Fan ───────────────────┘
   ```
2. **SSR inputs (3.3 V logic)** — SSR(+) → GPIO, SSR(−) → GND:
   - SSR1 → **GPIO 26** (heater)
   - SSR3 → **GPIO 27** (inlet fan)
   - SSR4 → **GPIO 13** (exhaust fan)
   - **GPIO 25 no longer wired to anything** (old SSR2 pin, now spare)
3. **HX711 + load cells** — four cells paralleled into one HX711:
   - Each cell: Red→E+, Black→E−, Green→A+, White→A−, Shield→GND (all E+/E−/A+/A− tied together)
   - HX711: DOUT→**GPIO 35**, SCK→**GPIO 32**, VCC→**3V3**, GND→GND
4. **SHT31** — SDA→**GPIO 21**, SCL→**GPIO 22**, VIN→3V3, GND→GND (addr 0x44)
5. **Power** — 220 VAC → PSU → **12 V rail** → buck converter input; buck output
   **5 V** → ESP32 **5V** pin (onboard regulator makes 3.3 V). Common ground:
   12 V PSU GND → buck GND → ESP32 GND → HX711 GND.

### Verify after editing

- Only 3 SSR devices in the parts list; no exhaust-outlet branch or 5 A fuse.
- GPIO 26/27/13 drive the three SSRs; GPIO 25 unconnected.
- Heater branch: `F1 10A → thermal cutoff → SSR1 → PTC heater (1500 W)`.
- Low-voltage side: PSU → 12 V → buck → 5 V → ESP32.

---

## Related

- Written pin-by-pin wiring plan: [`hardware-wiring.md`](hardware-wiring.md)
- BOM / procurement: [`../guides/bom.md`](../guides/bom.md)
- Pin definitions: `src/MultiDryerController/PINS_CONFIG.h`

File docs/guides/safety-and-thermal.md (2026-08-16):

# Safety & Thermal Design

The Multi Dryer switches 220 VAC loads in an enclosure that also holds an
ESP32, sensors, and a food-drying chamber. Safety is designed in **layers** —
no single failure may lead to an unsafe state (stuck-on heater, thermal
runaway, or mains exposure).

> Related: [`bring-up-checklist.md`](bring-up-checklist.md) Phase 0/4 ·
> [`troubleshooting.md`](troubleshooting.md) §2 ·
> [`../schematic/hardware-wiring.md`](../schematic/hardware-wiring.md) §2

---

## 1. Defense-in-Depth Layers

| Layer | Mechanism | Protects against |
|---|---|---|
| 1. Mechanical | Thermal cutoff (fuse/limit switch) in series with the heater branch | Stuck-on SSR, fan failure, firmware crash |
| 2. Electrical | Fuse per AC branch; opto-isolated SSRs | Overcurrent, short circuit, mains-to-logic faults |
| 3. Boot-time | Firmware forces every SSR pin LOW as the first step of `setup()` | SSR energizing during the boot window |
| 4. Firmware | **SHT31 vent guard**, PID output limits, TARE gate, manual/auto arbitration | Dead sensor → full-power heating; conflicting control |
| 5. User | Enclosure isolation, wiring separation, clear labeling | Electric shock, fire |

---

## 2. AC Power Distribution

```
AC-L ──┬─[F1 10A]──[Thermal cutoff]── SSR1 (load) ── PTC Heater ──┐
       ├─[F2  2A]── SSR3 (load) ── Inlet Fan ────────────────────┤── AC-N
       └─[F3  2A]── SSR4 (load) ── Exhaust Fan ──────────────────┘
```

- **Fuses:** 10 A on the heater branch (1500 W / 220 V ≈ 6.8 A → ~1.5×), 2 A on
  each fan branch. Sized ~1.5× steady-state current. There is **no separate
  outlet branch** — the exhaust fan (SSR4) provides venting.
- **Thermal cutoff (mandatory):** rated just above the maximum expected chamber
  temperature, wired **in series with the PTC heater** only. If the SSR sticks
  on or a fan dies, the cutoff opens the heater circuit mechanically.
- **Neutral/common:** all branches return to AC-N; no switching on the neutral.

---

## 3. SSR Strategy

| Item | Requirement |
|---|---|
| SSR input | 3–32 VDC (Fotek/Omron style) → driven directly by 3.3 V logic (5–10 mA) |
| SSR output | 220 VAC, **derated** — 3 × SSR-40DA **40 A** modules (heater 1500 W ≈ 6.8 A, fans ≈ 1 A; large headroom, minimal heat) |
| Isolation | Opto-isolated AC side — the mains never touches the ESP32 electrically |
| Fail-safe | Firmware forces every SSR input LOW at the top of `setup()` — outputs stay OFF until explicitly enabled |
| Thermal | Heat sinks on all SSRs; AC wiring separated from signal wiring |

Drive circuit per output:

```
ESP32 GPIO ── SSR input (+)      SSR input (−) ── GND
```

> **3.3 V-logic SSR inputs are required** — the ESP32 drives SSR(+) directly
> (3–32 VDC input types). If a module needs a higher drive level, use a
> 3.3 V-logic-compatible SSR rather than adding external driver circuitry.

---

## 4. Boot-Time Safety

1. Firmware sets every SSR pin `pinMode(OUTPUT); digitalWrite(LOW);` **as the first thing in `setup()`**, before WiFi/ESP-NOW init — no SSR can energize until the firmware explicitly enables it. (The 3-SSR build drives SSR1, SSR3, and SSR4 only.)
2. Pin selection avoids boot hazards: no strapping pins (0/2/4/5/12/15), no GPIO 14 (PWM burst at boot), no flash/UART0 pins — so an SSR can never be driven HIGH by default reset behavior.

---

## 5. Firmware Safety

### 5.1 SHT31 vent guard (the critical rule)
In `PID_CONFIG.h::pidCOMPUTE()` — if the temperature feedback is lost
(`!sht31OK`) while the PID is in AUTOMATIC:

```
PID_OUTPUT = 0
SSR1 (heater)  = OFF      SSR3 (inlet fan)  = OFF
SSR4 (exhaust fan) = ON                          ← vent instead of heat
```

**A dead sensor can never cause full-power heating.** The unit vents, `FLAG_SHT31`
clears on the HMI, and the status packet reflects the real SSR state.

### 5.2 Output limits & arbitration
- PID output clamped 0–5000 (`SetOutputLimits`) — the SSR drive is binary
  (heat vs. vent), so this bounds the duty model.
- Any **manual** HEATER/FAN/EXHAUST command **ends an active session first**
  (`espnow_link.h::handleCmd`) — manual and automatic control can never fight.

### 5.3 Calibration gate
TARE / CALIBRATE are ignored unless the state machine is **IDLE**, so a
boot-time TARE can't destroy a restored session's weight reference.

### 5.4 Restored sessions
On boot-resume, the PID restarts only for DRYING sessions and only if the SHT31
guard passes — a session resumed with a dead sensor vents, it doesn't heat.

---

## 6. Thermal Design

| Aspect | Guidance |
|---|---|
| Heater sizing | 1500 W PTC, matched to chamber volume and target drying temp |
| Airflow | Inlet fan runs whenever the heater is on (SSR1+SSR3 together) — no heater without airflow |
| Exhaust | Exhaust fan (SSR4) on when venting — removes humid air and excess heat |
| Chamber sensor | SHT31 near the product (not directly in heater blast) for accurate feedback |
| Over-temp option | Optional NTC thermistor on a spare ADC1 pin (GPIO 34/36/39) for a firmware high-limit cutoff — listed as a future enhancement |
| SSR cooling | Heat sinks + airflow past the SSR bank; keep AC wiring ≥ 6 mm from signal lines |

**Thermal cutoff test:** heat the limit switch to its rating → the heater branch
must clear. See `bring-up-checklist.md` §4.5.

---

## 7. Enclosure & User Safety

- 220 VAC → 12 V 5 A PSU feeding a 12 V → 5 V 3 A buck converter; the 5 V rail
  feeds the ESP32's 5V pin (onboard regulator makes 3.3 V).
- One common ground: 12 V PSU GND → buck GND → ESP32 GND → HX711 GND (tie HMI ground too, though it's wireless).
- Never route 220 V wiring near signal pins; use cable glands / separate ducting.
- Fuses accessible; thermal cutoff replaceable; clear labels on the enclosure.
- Live-wiring rule: **always unplug mains before opening or servicing.**

---

## 8. Failure-Mode Analysis

| Failure | Result without safeguards | Active safeguard | Result with safeguards |
|---|---|---|---|
| SSR1 sticks ON | Heater runs uncontrolled → fire | Thermal cutoff opens heater branch | Heater circuit physically cleared |
| Inlet fan fails (heater on) | Overheat, no airflow | Thermal cutoff + PID sees rising temp → output 0 → vent | Venting, heater off |
| SHT31 dies mid-cycle | PID heats blind at full power | Vent guard (heater OFF, vent ON) | Safe, vents; HMI shows SHT31 flag clear |
| Controller crashes/resets | SSRs hold last state (bad) | Firmware forces pins LOW at boot + re-inits MANUAL | All outputs OFF at reset |
| WiFi/ESP-NOW loss | Control link lost | Controller runs autonomously (state machine keeps safety rules) | Drying continues safely; HMI stale |
| Command burst floods controller | Dropped/lost commands | 8-slot ring buffer | No loss |
| Brown-out | Random SSR state | 5 V buck ≥ 3 A + bulk capacitance; watchdog resets to safe boot | OFF at boot |

---

## 9. Verification

- **Bring-up:** `guides/bring-up-checklist.md` — Phase 0 (pre-flight), Phase 1.2
  (fail-safe), Phase 4 (PID & thermal, incl. §4.4 vent-guard test and §4.5
  cutoff test), Phase 6 (soak).
- **Golden rule on the bench:** a dead SHT31 must result in **venting, never
  heating** — test this explicitly every bring-up (checklist §4.4).

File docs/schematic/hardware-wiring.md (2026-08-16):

# Multi Dryer — Hardware Wiring Plan (v1)

Target board: **ESP32 38-pin DevKitC** (ESP32-WROOM-32 module, no PSRAM — verify module type, see §5.3).
HMI board: **ESP32-S3 + touch** (separate board, communicates wirelessly via **ESP-NOW** — same transport the HMIDisplay reference already uses).

Design goal: every pin on the controller is **boot-safe** (no strapping/flash/boot-PWM pins) and **WiFi-safe** (no analog use on ADC2 pins, which become unusable when WiFi/ESP-NOW is active).

---

## 1. Pin Allocation (final)

| Function | GPIO | Board label | Notes |
|---|---|---|---|
| **SSR1 — PTC heater** (power stage) | **26** | D26 | clean digital output |
| **SSR3 — inlet air fan** | **27** | D27 | clean digital output |
| **SSR4 — exhaust fan** | **13** | D13 | clean digital output |
| **HX711 — DOUT** (load cell data) | **35** | D35 | input-only pin — perfect (read-only) |
| **HX711 — SCK** (load cell clock) | **32** | D32 | clean digital output |
| **SHT31 — temp/humidity (I2C)** | **21 (SDA), 22 (SCL)** | | hardware I2C; temp feedback for PID (FishDryer baseline); driver: `SHT31_CONFIG.h` |
| Spare digital | 16, 17, 18, 19, 23, 25, 33 | | 16/17 = WROOM-32 only (PSRAM on WROVER); 18/19/23 = default VSPI; 25 = freed ex-SSR2 pin |
| Spare input-only | 34, 36, 39 | | future analog sensors (ADC1, WiFi-safe) |
| **Avoid — strapping pins** | 0, 2, 4, 5, 12, 15 | | see §3.1 |
| **Avoid — flash pins** | 6, 7, 8, 9, 10, 11 | | connected to SPI flash inside module |
| **Avoid — UART0** | 1 (TX), 3 (RX) | | USB-serial for flashing/debug only |

> Only **3 SSRs** in this build: SSR1 (heater), SSR3 (inlet fan), SSR4 (exhaust
> fan). The exhaust outlet was dropped — venting is done by the exhaust fan
> (SSR4), and GPIO 25 (the old SSR2 pin) is free as spare digital.
>
> **Do not connect anything to GPIO 14** for outputs: it emits a PWM burst at boot (would glitch an SSR). GPIO 1/3 also drive HIGH at boot — keep them free for the serial monitor.

---

## 2. Wiring Diagrams

### 2.1 AC Power Side (220 V)

```
AC-L ──┬─[F1 10A fuse]───[Thermal cutoff]── SSR1 (load term.) ── PTC Heater ──┐
       ├─[F2  2A fuse]─── SSR3 (load term.) ── Inlet Fan ──────┤── AC-N
       └─[F3  2A fuse]─── SSR4 (load term.) ── Exhaust Fan ────┘
```

- **Fuse sizing:** 10 A on the heater branch (1500 W / 220 V ≈ 6.8 A → ~1.5×), 2 A
  on each fan branch. There is **no separate outlet branch** — the exhaust fan
  (SSR4) provides venting.
- **Thermal cutoff (mandatory):** a thermal fuse or bimetallic limit switch wired **in series with the PTC heater** branch, rated just above max chamber temperature. Protects against a stuck-on SSR or fan failure. Optionally add an NTC thermistor on a spare ADC1 pin (GPIO 34/36/39 — WiFi-safe) for a firmware over-temperature cutoff.

- Each SSR's **AC side is opto-isolated** from its DC input — the 220 V side never touches the ESP32 electrically.
- Use SSRs rated for **3–32 VDC input** (Fotek/Omron style) so the ESP32's 3.3 V logic drives them directly (≈5–10 mA).
- Mount SSRs on heat sinks; keep AC wiring physically separated from all low-voltage signal wiring (cable glands / separate ducting).

### 2.2 SSR Drive Circuit (per output × 3)

```
ESP32 GPIO ── SSR input (+)      SSR input (−) ── GND
```

- **Fail-safe is firmware-enforced:** every SSR pin is set `pinMode(OUTPUT); digitalWrite(LOW);` as the **first thing in `setup()`** (before WiFi/ESP-NOW init), so no SSR can energize until the firmware explicitly enables it.
- Verify the SSR's input triggers reliably at 3.3 V logic (3–32 VDC input types). If the module needs a higher drive level, use a 3.3 V-logic-compatible SSR rather than adding external driver circuitry.

### 2.3 Load Cell + HX711

```
Load cells (4 × 50 kg, summed full-bridge): wire each cell the same way and
parallel all four — Red→E+   Black→E−   Green→A+   White→A−   Shield→GND
(all E+ together, all E− together, all A+ together, all A− together)

HX711 module          ESP32 (38-pin)
  VCC      ──────────  3V3
  GND      ──────────  GND
  DOUT     ──────────  GPIO 35      (input-only pin — safe)
  SCK      ──────────  GPIO 32
  RATE/GND ──────────  leave default (10 SPS)
```

- The four 50 kg cells sum into **one bridge** on the single HX711 channel →
  200 kg total capacity. With typical 350 Ω cells the paralleled bridge loads the
  3V3 rail with only ~87 Ω (≈38 mA) — fine for the onboard regulator.
- Keep the load cell cables short, twisted, and away from the AC/SSR wiring (noise immunity). Add a 100 nF decoupling cap across HX711 VCC–GND.

### 2.4 Controller ⇄ HMI (ESP-NOW, wireless)

```
Controller (ESP32 38-pin)          HMI (ESP32-S3 + touch)
        ┌─────────────────┐                ┌─────────────┐
        │ WiFi STA + ESP-NOW ════════════► │ WiFi STA    │
        └─────────────────┘                └─────────────┘
               GND (both boards) ── common ground recommended
```

- **No signal wires between the boards.** Protocol header `src/MultiDryerController/espnow_protocol.h` is byte-identical to the HMIDisplay reference, so the two sides interoperate as-is.
- Controller link driver: `src/MultiDryerController/espnow_link.h` — sends **EspNowStatusPacket** at 1 Hz carrying state, SHT31 temp/humidity, load cell weight (kg), water loss, setpoint, PID output, runtime and EDT; receives **EspNowCmdPacket** commands — the full protocol set (drying control, PID, calibration, manual overrides) is implemented.
- **MAC setup (one-time):**
  1. Boot controller → serial prints `Controller MAC: XX:…`
  2. Paste into `CONTROLLER_PEER_MAC` in the HMI's `src/MultiDryerHMI/serial_protocol.cpp`
  3. Boot HMI → serial prints `Controller peer MAC: YY:…`
  4. Paste into `HMI_PEER_MAC` in the controller's `espnow_link.h`, re-flash controller
- Set both to the same channel (`ESPNOW_WIFI_CHANNEL`, default 1).
- **ESP-NOW is the ONLY board-to-board transport** — no UART and no I2C between controller and HMI (decision 2026-08-07). GPIO 16/17 stay free, and the SHT31 owns the I2C bus.
- The serial (UART0) ports of both boards are used **only** for local flashing/debug, never for inter-board comms.

### 2.5 SHT31 Temperature/Humidity (part of the build)

```
SHT31  SDA ── GPIO 21      SHT31  SCL ── GPIO 22      VIN ── 3V3      GND ── GND
```

- Address **0x44** (0x45 if ADDR tied HIGH). Driver: `src/MultiDryerController/SHT31_CONFIG.h` (non-blocking state machine, CRC-8, ported from the FishDryer baseline onto the hardware I2C bus).
- Temp feedback feeds PTC control/PID, and temp/humidity are reported to the HMI over ESP-NOW.

---

## 3. Boot Compatibility — Why This Allocation Is Safe

> Note: GPIO 21/22 (SHT31 I2C) are clean digital pins with no boot behavior — they are safe as an I2C bus.

### 3.1 Strapping pins avoided

| GPIO | Strapping behavior | Consequence if used carelessly |
|---|---|---|
| 0 | LOW at reset → download mode | device won't boot from flash |
| 2 | must be floating/LOW at reset | pull-ups (e.g., SSR input) can break flashing |
| 4 | JTAG source select | boot behavior changes with external pull |
| 5 | must be HIGH at reset | a pulldown on it can trap the board in SD boot |
| 12 | boot fails if HIGH at reset | external pull-ups can brick boot |
| 15 | must be HIGH at reset | pulldowns can hang boot |

None of 0/2/4/5/12/15 appear in the allocation.

### 3.2 Flash pins avoided

GPIO 6–11 are bonded to the module's SPI flash — never available. Not used.

### 3.3 No boot-PWM/HIGH pins used for outputs

GPIO 1, 3 (serial), 5, 14, 15 drive HIGH or PWM at reset. An SSR on GPIO 14 could click/pulse briefly at every power-on; we avoid that class entirely. All SSR lines are plain, clean GPIOs, and the firmware forces them LOW at the top of `setup()`, so outputs stay OFF until explicitly enabled.

### 3.4 UART0 untouched

GPIO 1/3 remain free → flashing and serial debugging always work with peripherals connected.

### 3.5 Verify with the boot checklist (§7)

---

## 4. WiFi / ESP-NOW Compatibility

1. **No analog reads on ADC2 pins.** With WiFi (or ESP-NOW) active, ADC2 (GPIO 4, 0, 2, 15, 13, 12, 14, 27, 25, 26) returns invalid values. The plan deliberately uses ADC2-capable pins (13/26/27; 25 stays spare) as **digital outputs only**, and the load cell path is fully digital (HX711). Nothing depends on ADC2 analog.
2. **Future analog sensors** must use ADC1 (GPIO 32–39): GPIO 34, 36, 39 stay reserved for that.
3. **ESP-NOW needs WiFi STA mode** (`WiFi.mode(WIFI_STA)`), which the reference HMI already does. No conflicts with the chosen pins.
4. If the controller ever connects to a real network (OTA, telemetry), same rules apply — no changes needed to the pin map.

---

## 5. Power & Isolation Notes

### 5.1 Low-voltage supply
- **220 VAC → 12 V / 5 A** mains PSU → 12 V rail.
- **12 V → 5 V / 3 A** buck converter → ESP32 **5V** pin. The DevKitC's onboard regulator makes 3.3 V.
- Optional 5 V for HX711: see below.

### 5.2 HX711 supply
- **HX711 VCC → 3V3** (recommended): direct logic levels, no level shifting. Slightly lower bridge excitation — fine for the 4× 50 kg paralleled bridge.
- **DOUT floats when the HX711 is unpowered** (GPIO 35 is input-only with no internal pull-up) — firmware must gate reads on `scale.is_ready()` (the FishDryer baseline already does) so a floating DOUT is never mistaken for a valid reading.

### 5.3 Verify module type (important!)
- 38-pin DevKitC boards ship with **WROOM-32** (GPIO 16/17 free) or **WROVER** (GPIO 16/17 used by PSRAM — do not touch them). The allocation above lists 16/17 as spare; nothing critical depends on them.

### 5.4 General safety
- One common ground: 12 V PSU GND → buck GND → ESP32 GND → HX711 GND. If the HMI is on a separate PSU, tie the two boards' grounds (ESP-NOW is wireless, but shared reference is safer for any shared lines).
- Fuses on every AC branch (§2.1), correct wire gauge, heatsinks on SSRs.
- Never route 220 V wiring near signal pins; keep ≥ 6 mm separation on any custom PCB.

---

## 6. Suggested BOM

| Item | Spec | Qty |
|---|---|---|
| ESP32 38-pin DevKitC (WROOM-32) | 38-pin, WROOM (verify) | 1 |
| SSR-40DA (3–32 VDC input / 220 VAC output) | Fotek-style 40 A, one per branch | 3 |
| PTC heater | 1500 W | 1 |
| Inlet + exhaust fans | 220 VAC axial fans | 2 |
| HX711 breakout | 24-bit ADC | 1 |
| Load cells | 4 × 50 kg, 4-wire (summed bridge) | 4 |
| SHT31 breakout | I2C temp/humidity, addr 0x44 | 1 |
| 220 VAC → 12 V PSU | 5 A (60 W) | 1 |
| 12 V → 5 V buck converter | 3 A | 1 |
| Fuses | 10 A / 2 A / 2 A | 3 |
| Wire, terminals, heatsinks, enclosure | — | — |

---

## 7. Verification Checklist

1. **Boot test:** with everything connected, open the serial monitor — board must boot normally (no download-mode loop, no crash). 
2. **Fail-safe test:** with everything connected, power on and confirm **no SSR/load toggles** during the boot window — the firmware forces every SSR pin LOW at the top of `setup()`, before WiFi/ESP-NOW init.
3. **Flash test:** `esptool.py chip-id` / Arduino upload must succeed with peripherals attached (proves no strapping pin is loaded down).
4. **WiFi/ESP-NOW test:** enable ESP-NOW (or run `WiFi.scanNetworks()`) with SSRs + HX711 connected — no hangs, and control still works (proves ADC2/WiFi rule is not violated).
5. **Load cell test:** send `TARE` then `CALIBRATE:<kg>` (FishDryer protocol) — weight reads correctly on the HMI.
6. **Output test:** toggle SSR1/SSR3/SSR4 (populated SSRs) from the HMI one at a time; verify with a multimeter/clamp meter on the AC side.
7. **Thermal test:** confirm the thermal cutoff clears the heater branch at its rated temperature (simulate by heating the limit switch).
8. **setup() order test:** confirm SSR pins are forced LOW at the top of `setup()`, before WiFi/ESP-NOW init — no SSR toggles during boot.

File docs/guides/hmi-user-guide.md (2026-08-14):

# HMI User Guide

How to use the touchscreen HMI (ESP32-S3 + 7″ display, LVGL). The HMI is the
**face** of the Multi Dryer — the controller makes all control decisions; the
HMI sends commands over ESP-NOW and displays what the controller reports.

> Implementation: [`src/MultiDryerHMI/`](../../src/MultiDryerHMI/) ·
> Protocol: [`../api/espnow-protocol.md`](../api/espnow-protocol.md)

---

## 0. Screen Map

```
BOOT ──(auto)──► DASHBOARD ──┬──► CONTROL ──(back)──► DASHBOARD
                             ├──► ANALYTICS ──(back)─► DASHBOARD
                             ├──► DIAGNOSTICS ─(back)► DASHBOARD
                             └──► HOW TO USE  ─(back)► DASHBOARD
```

Navigation from the dashboard (bottom nav bar):
**⚙ Control · ☰ Analytics · ◉ Diag** — plus **HOW TO USE** from the
dashboard/control area.

---

## 1. Boot Screen

- Splash with the **Multi-Purpose Dryer** branding, subtitle *"Smart Drying System"*.
- Shows `Initializing...` while the HMI boots and sends its boot-time **TARE**
  to the controller, then auto-advances to the **Dashboard**.
- If the controller never answers, the dashboard shows stale/`--` values — see
  the [troubleshooting guide](troubleshooting.md) §1.

---

## 2. Dashboard (main screen)

Live overview, refreshed from the 1 Hz status packet (UI redraw every ~2 s):

| Area | Shows |
|---|---|
| State badge | **IDLE / DRYING / PAUSED / COMPLETE** |
| Temperature | Big current reading + **Target: XX °C** |
| Humidity | Current %RH |
| Weight | Current product weight (kg) |
| Water Loss | Progress bar + % |
| Relays | Heater / Fan / Exhaust indicator lights (real SSR state) |
| Elapsed | Runtime (controller-authoritative, pause-aware) |
| EDT | Estimated time to completion (`---` while estimating) |

### Bottom-bar buttons (state-driven)

| State | Buttons shown |
|---|---|
| IDLE | ▶ **START** (green) |
| DRYING | ■ **STOP** (red) + ⏸ **PAUSE** |
| PAUSED | ■ **STOP** only (resume lives on the Control screen) |
| COMPLETE | ▶ **START** (next session) |

> **START from IDLE** is a *quick start*: it sends the current target
> temperature + water-loss target, then `START_DRYING` (50 ms apart), so a
> session never starts with setpoint 0 or auto-complete off.
> **PAUSED shows no START** — pressing it would silently *restart the session
> fresh* and destroy the water-loss reference. Use **RESUME** on the Control
> screen instead.

---

## 3. Control Screen

### 3.1 Drying Preset (one-tap temperature)
| Preset | Setpoint |
|---|---|
| 🐟 **Tuyo** | 60 °C |
| 🐟 **Danggit** | 60 °C |
| 🦑 **Pusit** | 50 °C |
| **Others** | Custom (use the +/− buttons) |

### 3.2 Manual temperature row
`-5  −  +  +5` around the current setpoint — each tap sends
`SET_TEMPERATURE` immediately (and persists to NVS on the controller).

### 3.3 Target Water Loss
Slider (with % label) — sets the **auto-complete** target. The controller stops
the session when this % is reached. 0% = auto-complete off.

### 3.4 Drying Mode / session buttons
| Button | Sends | Visible when |
|---|---|---|
| ▶ **START** | `START_DRYING` | IDLE / COMPLETE |
| ⏸ **PAUSE** | `PAUSE_DRYING` (all SSRs off, session saved) | DRYING |
| ▶ **RESUME** | `RESUME_DRYING` (PID back on) | PAUSED |
| ■ **STOP** | `STOP_DRYING` (session cleared) | DRYING / PAUSED |

Buttons give **instant feedback** (optimistic state) and are corrected by the
next 1 Hz status packet — that's normal, not a bug.

---

## 4. Analytics Screen

Tabbed history charts (LVGL charts, fed from the status stream):
- **Temperature (°C)** — chamber temperature over time
- **Humidity (%RH)** — relative humidity over time
- **Weight (kg)** — product weight trend (sessions show the water-loss curve)

Data is accumulated while the HMI runs; it resets on HMI reboot (no
cross-reboot history storage yet).

---

## 5. Diagnostics Screen

### 5.1 Sensor Status / Power / I2C / System cards
Live status: SHT31 (temp/humidity, CRC-valid), load cell weight, PID state,
I2C device list, uptime, packet counters, and last status-packet time.

### 5.2 ⚙ CALIBRATE SCALE (guided 3-step wizard)
1. **Step 1** — Empty the scale and tap **TARE SCALE** (controller must be IDLE).
2. **Step 2** — Set the known reference weight with `− / +`.
3. **Step 3** — Place the weight, then tap **CALIBRATE**.

→ Full details: [`calibration-guide.md`](calibration-guide.md).

### 5.3 ⟳ RUN SENSOR TEST
Forces an immediate status packet (SHT31 + load cell read) — handy for
confirming the link and sensors live.

> ⚠️ TARE/CALIBRATE are **ignored while a session is active** — the controller
> gates them to IDLE. Press STOP first.

---

## 6. HOW TO USE (instruction guide)

A 10-step illustrated quick-reference (static cards): prepare → load tray →
tare → set temperature → set water-loss target → start → monitor → complete →
unload/store → clean & maintain.

---

## 7. Alerts (popups)

| Popup | Trigger | Buttons |
|---|---|---|
| ⚠️ Warning | Sensor loss / abnormal state (e.g. SHT31 absent) | **ACKNOWLEDGE** |
| 🎉 DRYING COMPLETE | Controller reaches COMPLETE while HMI is running | **OK** (shows water loss % + total time) |

---

## 8. Button Semantics Summary

| Button | Command | Controller effect |
|---|---|---|
| START | `START_DRYING` | New session: initial weight captured, PID on |
| STOP | `STOP_DRYING` | All SSRs off, session cleared |
| PAUSE | `PAUSE_DRYING` | All SSRs off, session saved (resumable, even across reboot) |
| RESUME | `RESUME_DRYING` | PID back on, runtime continues |
| +/−, presets | `SET_TEMPERATURE` | Setpoint set + persisted |
| Slider | `SET_WATER_LOSS` | Auto-complete target set + persisted |
| TARE / CALIBRATE | `TARE_SCALE` / `CALIBRATE_SCALE` | Only in IDLE; factor saved to NVS |

---

## 9. First-Use Workflow (recommended)

1. **Load** the product on the tray; close the chamber door.
2. **Tare** (Diagnostics → TARE SCALE) with the product loaded.
3. **Configure** (Control): pick a preset or set temperature + water-loss target.
4. **Start** (Dashboard or Control) — watch temperature rise to setpoint.
5. **Monitor** — dashboard shows temp/humidity/weight/water loss/EDT.
6. **Completion** — the dryer stops itself; popup shows the result.
7. **Unload & clean** per the HOW TO USE steps.

---

## 10. Notes & Known Gaps

- **Manual heater/fan/exhaust control:** available on the Control screen —
  switching to **Manual mode** reveals Heater / Inlet Fan / Exhaust switches
  (`sendHeaterControl` / `sendFanControl` / `sendExhaustControl`). Any manual
  command ends an active session first, so manual and automatic control never fight.
- **History** resets on HMI reboot (analytics buffer is RAM-only).
- **Elapsed/EDT** come from the controller — if the HMI reboots mid-session, the
  numbers are correct again within 1 s (no local clock guessing).

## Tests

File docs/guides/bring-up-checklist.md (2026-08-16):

# Bring-Up / Boot Checklist

Ordered hardware bring-up procedure for the Multi Dryer. Go top to bottom —
each phase depends on the previous one. Tick boxes as you pass each check.

> References: wiring plan [`../schematic/hardware-wiring.md`](../schematic/hardware-wiring.md),
> protocol [`../api/espnow-protocol.md`](../api/espnow-protocol.md),
> stack [`../stacks/tech-stack.md`](../stacks/tech-stack.md).

---

## Phase 0 — Pre-Flight (bench, unpowered)

- [ ] **0.1** Visual check: no solder bridges, shorts, or cold joints on SSR inputs, HX711, SHT31.
- [ ] **0.2** Continuity: each GPIO → SSR input is wired directly, with no short to GND or the AC side.
- [ ] **0.3** Power rails separated: 220 VAC side never adjacent to signal wires (< 6 mm rule).
- [ ] **0.4** Fuses fitted on every AC branch (10 A heater / 2 A / 2 A fans).
- [ ] **0.5** Thermal cutoff wired **in series with the PTC heater** branch.
- [ ] **0.6** Load cells (4 × 50 kg) wired as a summed full-bridge — each cell Red→E+, Black→E−, Green→A+, White→A−, Shield→GND; all E+/E−/A+/A− paralleled into the one HX711 channel.
- [ ] **0.7** SHT31 on the I2C bus: SDA→21, SCL→22, VIN→3V3, GND→GND, addr 0x44 (0x45 if ADDR tied HIGH).
- [ ] **0.8** Bench meter / clamp meter ready for AC-side output checks.

---

## Phase 1 — Controller Only (no AC loads, no HMI)

**Goal:** prove the board boots, the pins are safe, and the sensors read.

### 1.1 Boot test
- [ ] **1.1a** Flash the controller sketch (`src/MultiDryerController`).
- [ ] **1.1b** Open the serial monitor (115200) — board boots normally: **no download-mode loop, no crash/reboot**.
- [ ] **1.1c** Boot banner appears in order: pins → SHT31 → load cell → PID → drying → ESP-NOW.

### 1.2 Fail-safe test
- [ ] **1.2a** After boot, measure each SSR input — must read **LOW** (firmware forces pins LOW at the top of `setup()`).
- [ ] **1.2b** Heater and fans stay off during the ~1 s boot window (no SSR clicks).
- [ ] **1.2c** Firmware forces SSR pins LOW first thing in `setup()` — verify no HIGH glitch on populated SSR pins GPIO 26/27/13.

### 1.3 Flash test (with peripherals attached)
- [ ] **1.3a** `esptool.py chip-id` / Arduino upload **succeeds** with SSRs + HX711 + SHT31 all connected (proves no strapping pin is loaded down).
- [ ] **1.3b** Repeat upload 3× — no download-mode traps.

### 1.4 Sensor tests
- [ ] **1.4a** SHT31: serial shows plausible temp (~room temp) and humidity; `[SHT31] OK` (or the state-machine status line shows `temp=…`).
- [ ] **1.4b** SHT31 CRC: no CRC failures in a 2-minute window.
- [ ] **1.4c** Load cell: `TARE` via the HMI or serial command → weight ≈ 0.000 kg.
- [ ] **1.4d** Load cell: `CALIBRATE:<kg>` with a known weight → reading tracks within ±2%.

---

## Phase 2 — WiFi / ESP-NOW

- [ ] **2.1** Controller serial prints `[ESP-NOW] Controller MAC: XX:…` and `Link ready`.
- [ ] **2.2** Run `WiFi.scanNetworks()` (or just leave ESP-NOW active) with all peripherals connected — **no hangs**, control still responsive (proves the ADC2/WiFi rule isn't violated).
- [ ] **2.3** Note the controller MAC.

### 2.4 HMI pairing
- [ ] **2.4a** Flash the HMI sketch (`src/MultiDryerHMI`) on the ESP32-S3 — display initializes (splash → boot screen).
- [ ] **2.4b** HMI serial prints its own MAC.
- [ ] **2.4c** Paste controller MAC into `CONTROLLER_PEER_MAC` (HMI `serial_protocol.cpp`), re-flash HMI.
- [ ] **2.4d** Paste HMI MAC into `HMI_PEER_MAC` (controller `espnow_link.h`), re-flash controller.
- [ ] **2.4e** Both serial monitors show clean sends; dashboard shows **live values** (temp/humidity/weight) updating ~1 Hz.
- [ ] **2.4f** No `Add peer FAILED` / `Send failed — check …_PEER_MAC` messages.

---

## Phase 3 — Outputs (one at a time, AC connected)

> Verify each with a multimeter/clamp meter on the AC side. Watch current draw.

- [ ] **3.1** `HEATER_ON` → SSR1 energizes (PTC) **and** SSR3 (inlet fan) — airflow with heat.
- [ ] **3.2** `HEATER_OFF` → all outputs off.
- [ ] **3.3** `FAN_ON` → SSR3 (inlet fan) only; `FAN_OFF` → off.
- [ ] **3.4** `EXHAUST_ON` → SSR4 (exhaust fan); `EXHAUST_OFF` → off.
- [ ] **3.5** Dashboard indicators (Heater/Fan/Exhaust) match the real SSR states within 1 s.

---

## Phase 4 — PID & Thermal

- [ ] **4.1** Set a setpoint (e.g. 60 °C) on the HMI → heater cycles; temperature rises toward the setpoint.
- [ ] **4.2** Temperature settles near the setpoint without excessive overshoot (tune KP/KD if not).
- [ ] **4.3** Above target: PID output → 0, unit vents (SSR4 on, heater off).
- [ ] **4.4** **Safety guard:** unplug/disable the SHT31 mid-cycle → heater forced OFF, unit vents, HMI flags SHT31 absent (`FLAG_SHT31` clear).
- [ ] **4.5** **Thermal cutoff:** heat the limit switch to its rating → heater branch clears (circuit trips) — no heating until reset.

---

## Phase 5 — State Machine & Persistence

- [ ] **5.1** `START_DRYING` → state DRYING, runtime counts, water loss decreases as weight drops.
- [ ] **5.2** `PAUSE_DRYING` → all SSRs off, state PAUSED; runtime **freezes**.
- [ ] **5.3** `RESUME_DRYING` → PID back on, runtime continues.
- [ ] **5.4** `STOP_DRYING` → state IDLE, session cleared.
- [ ] **5.5** **Auto-complete:** set a water-loss target, let weight reach it → state COMPLETE, outputs off, HMI shows the completion dialog.
- [ ] **5.6** **Reboot-resume:** start a session, power-cycle the controller → on boot it resumes (DRYING with PID, or stays PAUSED); weight reference intact (water loss not corrupted).
- [ ] **5.7** **Config persistence:** set temperature + water-loss target, reboot → values restored even with no session active.
- [ ] **5.8** **TARE gate:** while a session is active, a boot-time TARE is **ignored** (weight/water loss unchanged).

---

## Phase 6 — Final Integration Sign-Off

- [ ] **6.1** Full cycle from the HMI: configure → START → PAUSE → RESUME → auto-COMPLETE → STOP.
- [ ] **6.2** 30-minute soak: no resets, no sensor lockups, temperature stable, water loss tracking.
- [ ] **6.3** Log a full run in the diagnostics screen (analytics fields populated).
- [ ] **6.4** Record results: date, firmware hashes, tuned KP/KD values, calibration factor → update this checklist.

---

## Troubleshooting Quick Reference

| Symptom | Likely cause | Fix |
|---|---|---|
| Board stuck in download mode / won't boot | A strapping pin loaded down (0/2/4/5/12/15) | Check wiring on strapping pins; remove pull-ups |
| SSR clicks at power-on | GPIO 14 used as an output (PWM burst at boot) | Move to a clean GPIO; never use GPIO 14 |
| No SHT31 data | Wrong pins, wrong addr | Check SDA/SCL, try address 0x45 |
| Weight reads garbage / floats | HX711 offset drift or floating DOUT | `TARE`; ensure HX711 powered; check DOUT/SCK |
| No status packets on HMI | Peer MACs not set / channel mismatch | Complete §2.4; both on channel 1 |
| Heater never on | Setpoint 0 / SHT31 lost (vent guard) | Send `SET_TEMPERATURE`; check sensor |
| Session resurrects as DRYING after completion | Old NVS session marker | Press STOP after COMPLETE; clear NVS if needed |

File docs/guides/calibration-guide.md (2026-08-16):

# Load Cell Calibration Guide

How to calibrate the HX711 + load cell on the Multi Dryer controller, and how
the calibration persists.

> Implementation: [`src/MultiDryerController/LOADCELL_CONFIG.h`](../../src/MultiDryerController/LOADCELL_CONFIG.h)
> (bogde/HX711 library, reads in kg, factor persisted in NVS).

---

## 1. Background — what gets calibrated

The HX711 reads raw counts from the load cell. Two values turn raw counts into
kilograms:

| Value | What it is | Where it lives |
|---|---|---|
| **Calibration factor** | Counts per kg (`scale.get_scale()`) — scales raw ADC counts to weight | NVS namespace `loadcell`, key `factor` |
| **Offset (zero reference)** | The raw count read with nothing on the scale (`scale.get_offset()`) | NVS namespace `drying`, key `hxoff` (saved with every drying session) |

> This rig uses **4× 50 kg load cells wired as a summed full-bridge** on the one
> HX711 channel (200 kg total capacity). The procedure below calibrates the
> combined signal — exactly the same as with a single cell.

- **Factor** is set by `CALIBRATE:<kg>` and restored automatically on boot.
- **Offset** is set by `TARE`. It is *also* captured with every drying session
  (with the initial weight), so a mid-drying reboot restores the exact zero
  reference — no re-tare, even after a power cycle.

> ⚠️ **TARE / CALIBRATE are only accepted while the state machine is IDLE.**
> If a session is active (or was restored), the commands are ignored — this
> protects the water-loss reference.

---

## 2. When to calibrate

- **First bring-up** — always (the default factor `-10697.956054f` is a starting point from the reference baseline, not your rig).
- **After any mechanical change** — moving the load cell, changing the tray/platform, re-mounting.
- **When readings drift** — weight reading off by a consistent percentage → recalibrate the factor; off by a consistent *amount* → re-tare.
- **Periodically** — every few weeks of use, or after any heavy load/shock to the cell.

---

## 3. Prerequisites

- [ ] Controller running, state machine **IDLE** (no session active — check the HMI dashboard shows IDLE).
- [ ] HX711 powered and connected (DOUT→GPIO 35, SCK→GPIO 32) — serial should say `Load cell ready (kg)`.
- [ ] A known-weight object (a verified 1 kg, 2 kg, or 5 kg weight; a digital kitchen scale to check anything else).
- [ ] Nothing resting on the scale, and the platform must be **free to move** (not touching the enclosure).

---

## 4. Procedure (recommended: from the HMI)

The HMI sends the same commands over ESP-NOW (`CMD_TARE_SCALE` /
`CMD_CALIBRATE_SCALE`); the diagnostics screen is the usual place.

### Step 1 — Tare (zero)
1. Make sure the scale is **empty** and the platform is stable.
2. Send **TARE** (HMI diagnostics button, or `CMD_TARE_SCALE`).
3. Expected serial: `Load cell tared. Place known weight, then send CALIBRATE:<kg>.`
4. Expected HMI weight: **0.000 kg** (give it ~1 s to settle).

### Step 2 — Place the known weight
1. Center the known weight on the platform.
2. Wait ~2 s for the reading to stabilize.
3. Confirm the HMI shows roughly the known weight (it won't be exact yet — that's what Step 3 fixes).

### Step 3 — Calibrate with the known mass
1. Send **CALIBRATE** with the known mass in kg (e.g. `CALIBRATE:2` for a 2 kg weight).
2. Expected serial:
   ```
   --- Calibration complete ---
   Factor <value> saved to NVS.
   ```
3. Expected HMI weight: the reading should now match the known weight within ±2%.

### Step 4 — Verify
1. Remove the weight → HMI returns to ~0.000 kg (re-tare if slightly off).
2. Put the weight back → reads the known mass.
3. Repeat once more — readings must be repeatable.

> **Alternative — serial only:** the FishDryer protocol accepts the same
> commands on the controller's serial line. If you're testing without the HMI,
> use the serial monitor instead. Both paths end at `tareLoadCell()` /
> `calibrateLoadCell()`, so the result is identical.

---

## 5. How the factor is stored

```cpp
// LOADCELL_CONFIG.h
Preferences prefs;
prefs.begin("loadcell", false);          // read-write
prefs.putFloat("factor", scale.get_scale());
prefs.end();
```

- Stored in **NVS** (wear-leveled, native ESP32 storage) — the Nano baseline's
  EEPROM equivalent.
- **Restored on boot** in `initLoadCell()` if the saved value is valid
  (`0 < factor < 999999` and finite); otherwise the default factor
  `-10697.956054f` is used and serial reminds you to calibrate.
- The factor is **not** affected by drying sessions (session NVS only stores
  the offset/zero reference).

---

## 6. Troubleshooting

| Symptom | Cause | Fix |
|---|---|---|
| `WARNING: HX711 not responding!` at boot | Wiring / power / too little wait | Check DOUT=35, SCK=32, VCC=3V3/5V, GND; let it power-stabilize |
| Weight reads **negative** | Wrong factor sign, or clamped noise | Re-calibrate; `readLoadCell()` clamps negatives to 0 anyway |
| Reading off by a consistent **%** | Stale factor (e.g. after platform change) | Re-run CALIBRATE with a known weight |
| Reading off by a consistent **amount** | Offset drift (temperature, mechanical) | Re-TARE (IDLE only) |
| CALIBRATE "does nothing" | Session active → gated | Press STOP first, then calibrate |
| Jittery readings | Vibration / noise / too few samples | Stabilize platform; `LOADCELL_SAMPLES` = 3; tie HX711 RATE to 3.3 V for 80 SPS |
| Water loss wrong after a reboot mid-drying | TARE happened during the session (destroyed reference) | Shouldn't happen — TARE is gated; if it did, NVS was cleared/older firmware |

---

## 7. Calibration log

Record every calibration so drift is visible over time:

| Date | Firmware | TARE'd (Y/N) | Known mass (kg) | Saved factor | Verified ±2% |
|---|---|---|---|---|---|
| | | | | | |

---

## 8. Related

- Load cell driver: [`LOADCELL_CONFIG.h`](../../src/MultiDryerController/LOADCELL_CONFIG.h)
- Wiring: [`../schematic/hardware-wiring.md`](../schematic/hardware-wiring.md) §2.3
- Commands: [`../api/espnow-protocol.md`](../api/espnow-protocol.md) §3.1 (`0x40` TARE, `0x41` CALIBRATE)
- Bring-up: [`bring-up-checklist.md`](bring-up-checklist.md) Phase 1.4

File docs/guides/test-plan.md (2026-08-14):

# Test Plan — Multi Dryer

Verification strategy for the firmware: **host-side unit tests** for pure logic
(protocol + state machine), **command-handler tests** for the ESP-NOW edge cases,
and **HMI screen checks**. Hardware bring-up is covered separately by
[`bring-up-checklist.md`](bring-up-checklist.md) — this plan is the software layer
that runs *before and alongside* it.

> **Current state:** no test harness is committed yet — this plan is the spec for
> one. The state machine and protocol headers are written to be host-compilable
> with small stubs (same technique the headless screenshot renderer uses locally
> in `sim/`). Build the harness, fill the tables below, and run after every change
> to `espnow_protocol.h`, `DRYER_STATE.h`, or `espnow_link.h`.

---

## 1. Test Levels

| Level | What | Where | When |
|---|---|---|---|
| **Unit (host)** | Protocol structs/checksum, state machine transitions & math | Native build with stubs (`Serial`, `millis()`, `Preferences`, `scale`) | Every commit touching the shared header or state machine |
| **Command handler (host)** | `handleCmd` gating, ring buffer, arbitration | Same harness, fake `getDryerState()`/`startPID()` | Same |
| **HMI screen (visual)** | Every screen renders, navigation works, preset manager CRUD | Headless renderer (local `sim/`) + on-device | After any UI change; on-device at bring-up |
| **Hardware (bench)** | Boot, fail-safe, sensors, outputs, PID, thermal | Real rig | [`bring-up-checklist.md`](bring-up-checklist.md) |

---

## 2. Unit Tests — Protocol (`espnow_protocol.h`)

Both halves include this header — it must stay **byte-identical** (the copies drift
at your peril: struct sizes mismatch and every packet is rejected).

| ID | Test | Procedure | Expected |
|---|---|---|---|
| P1 | Struct sizes | `sizeof(EspNowStatusPacket)` / `sizeof(EspNowCmdPacket)` | **38** / **7** (packed, no padding) |
| P2 | Checksum vector | XOR a known byte array, compare to hand-computed value | Matches |
| P3 | Valid status packet | Fill all fields, set `checksum = espnowStatusChecksum()`, call `espnowStatusValid()` | `true` |
| P4 | Corrupted payload | Flip one byte mid-packet (not checksum), recompute nothing | `false` |
| P5 | Corrupted checksum | Flip only the checksum byte | `false` |
| P6 | Wrong type | Set `packetType` ≠ `ESPNOW_PKT_STATUS` with a valid checksum | `false` (type gate) |
| P7 | Cmd packet validity | Same as P3–P6 for `EspNowCmdPacket` / `espnowCmdValid()` | Per case |
| P8 | Header sync | `diff` the two `espnow_protocol.h` copies (controller vs HMI) | Identical |

---

## 3. Unit Tests — State Machine (`DRYER_STATE.h`)

Host harness with stubs: `millis()` returns a scripted clock, `readLoadCell()`
returns a scripted weight, `Preferences` backed by a RAM map, `Serial` a no-op
logger. Drive `updateDrying()` at 1 Hz by advancing the clock.

### 3.1 Transitions

| ID | Test | Procedure | Expected |
|---|---|---|---|
| S1 | IDLE → DRYING | `startDrying()` from IDLE | State `DRYING`, initial weight captured, PID started |
| S2 | Start while already DRYING | `startDrying()` twice | Second call is a no-op (stays DRYING) |
| S3 | DRYING → PAUSED | `pauseDrying()` | State `PAUSED`, PID stopped (all SSRs off) |
| S4 | PAUSED → DRYING | `resumeDrying()` | State `DRYING`, PID restarted |
| S5 | Resume when not PAUSED | `resumeDrying()` from IDLE | No-op |
| S6 | DRYING → COMPLETE | Drive weight to the water-loss target | Auto-completes: state `COMPLETE`, PID stopped |
| S7 | Any → IDLE | `stopDrying()` | State `IDLE`, session cleared, PID stopped |
| S8 | Restart from PAUSED | `startDrying()` while PAUSED | Fresh session (new initial weight, runtime reset) |

### 3.2 Water-loss math

| ID | Test | Procedure | Expected |
|---|---|---|---|
| W1 | Basic math | initW = 10.0 kg, weight = 8.0 kg | Water loss **20.0 %** |
| W2 | Negative clamp | weight > initW (gained weight / tare drift) | Clamped to **0.0 %** |
| W3 | Upper clamp | weight → 0 | Clamped to **100.0 %** |
| W4 | No usable init | initW ≤ 0.01 kg | Water loss stays **0.0 %** |
| W5 | Fresh-session reset | Stop → start with new weight | initW re-captured, loss resets to 0 |

### 3.3 Runtime & EDT

| ID | Test | Procedure | Expected |
|---|---|---|---|
| R1 | Accumulation | Advance 10 s in DRYING | `runtimeSeconds == 10` |
| R2 | Pause freezes | Pause, advance 30 s, resume | Runtime continues from 10 s (no pause drift) |
| R3 | EDT estimate | loss 10 % at 100 s, target 40 % | EDT ≈ (40−10)/(10/100) = **300 s** |
| R4 | EDT unknown rate | loss 0 % (rate < 0.0001 %/s) | EDT = **0** (unknown) |
| R5 | EDT after complete | Auto-complete reached | EDT = **0** |

### 3.4 NVS persistence & restore

| ID | Test | Procedure | Expected |
|---|---|---|---|
| N1 | No magic | Fresh namespace (magic absent) | No restore; state IDLE |
| N2 | Config-only restore | Saved marker IDLE + setpt/wlTgt | Setpoint & target restored, no session |
| N3 | Resume DRYING | Marker DRYING + initW/runMs/hxoff | State `DRYING`, runtime restored, HX711 offset re-applied, PID restarted |
| N4 | Resume PAUSED | Marker PAUSED | State `PAUSED`, PID **not** restarted |
| N5 | Config persist scope | `persistDryerConfig()` then inspect keys | Writes only `magic`/`wlTgt`/`setpt` — **never** `state`/`initW`/`runMs`/`hxoff` |
| N6 | Complete clears session | Auto-complete then inspect marker | `state` marker = IDLE (no resurrection on next boot) |
| N7 | Save cadence | Drying > 30 s, `_lastSaveMs` throttle | Session re-saved every ~30 s, not every tick |

---

## 4. Command-Handler Tests (`espnow_link.h` `handleCmd`)

Host harness with fake `getDryerState()` and spy `startPID()/stopPID()`/SSR flags.

| ID | Test | Procedure | Expected |
|---|---|---|---|
| C1 | TARE in IDLE | State IDLE, send `CMD_TARE_SCALE` | Accepted (scale tared) |
| C2 | TARE gated | State DRYING/PAUSED/COMPLETE, send TARE | **Ignored** (would destroy the zero reference) |
| C3 | CALIBRATE gated | Same gate as C2 | Accepted only in IDLE |
| C4 | Set temp | `CMD_SET_TEMPERATURE` with value | Setpoint updated **and** config persisted |
| C5 | Set water loss | `CMD_SET_WATER_LOSS` with value | Target updated, clamped 0–100, config persisted |
| C6 | Manual ends session | DRYING, send `CMD_HEATER_ON` | Session stopped (IDLE) **first**, then heater forced on |
| C7 | Manual in IDLE | IDLE, send `CMD_HEATER_ON`/`FAN_ON`/`EXHAUST_ON` | SSR flags reflect the override |
| C8 | Ring buffer order | Push 8 commands, drain | FIFO order, none lost |
| C9 | Ring buffer overflow | Push 10 commands, drain | First 8 kept (no corruption), 9th/10th dropped safely |

---

## 5. HMI Screen Checks

### 5.1 Automated (headless renderer — local `sim/`)

Rebuild the renderer and regenerate `docs/ui/*.png` after UI changes; visually
diff the outputs against the committed previews.

| ID | Screen | Check |
|---|---|---|
| H1 | Boot | "Multi-Purpose Dryer" title + subtitle render |
| H2 | Dashboard (idle & drying) | Live values, gauge needle, START/STOP/SET TEMP/HOW TO USE buttons |
| H3 | Control | Preset row from saved list, Custom, **+ Add** opens manager |
| H4 | Preset manager | Add (name + temp + water-loss), list with delete, keyboard works |
| H5 | Analytics | Temp/humidity/weight charts draw curves with data |
| H6 | Diagnostics | Status fields, TARE/CALIBRATE buttons |
| H7 | HOW TO USE | Opens from dashboard, 10 step cards, back arrow returns |

### 5.2 On-device (at bring-up, after `bring-up-checklist.md` §2.4 pairing)

- Every nav path: Dashboard ⇄ Control ⇄ Analytics ⇄ Diagnostics, Dashboard → HOW TO USE → back.
- Preset lifecycle: add → appears in row → tap applies temp + water-loss on the
  controller (verify via serial) → delete → gone after HMI reboot (NVS).
- Optimistic UI: button press gives instant feedback; the 1 Hz status packet
  corrects it within a second.
- Completion popup appears when the controller auto-completes.

---

## 6. Regression Rules

- **After any change** to `espnow_protocol.h` in either folder: run P1–P8 **and**
  the `diff` (P8) — the copies must stay identical.
- **After any change** to `DRYER_STATE.h` / `espnow_link.h`: run the full unit
  suite (S, W, R, N, C).
- **After any HMI screen change**: regenerate screenshots (H1–H7) and re-run the
  on-device nav check at next flash.
- Report results in the commit message or PR — the bring-up checklist §6.4 records
  hardware results.

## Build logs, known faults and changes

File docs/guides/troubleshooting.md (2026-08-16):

# Troubleshooting Guide

Systematic fixes for the most common Multi Dryer problems. Each section follows
**Symptom → Likely cause → Fix**, and ends with how to diagnose it.

> Related: [`bring-up-checklist.md`](bring-up-checklist.md) (ordered verification),
> [`calibration-guide.md`](calibration-guide.md) (load cell),
> [`../api/espnow-protocol.md`](../api/espnow-protocol.md) (packets & commands).

---

## 1. Communication — MAC Pairing & No Status Packets

### 1.1 No packets flow between controller and HMI

| Symptom | Likely cause | Fix |
|---|---|---|
| HMI dashboard stuck on `--` / stale values | Peer MACs are still the zero placeholders `{0x00,…}` | Complete the 4-step pairing (§1.2) |
| Controller logs `Add peer FAILED — is HMI_PEER_MAC set?` | `HMI_PEER_MAC` (controller `espnow_link.h`) not pasted | Paste the HMI's MAC, re-flash the controller |
| Controller logs `[ESP-NOW] Send failed — check CONTROLLER_PEER_MAC` | `CONTROLLER_PEER_MAC` (HMI `serial_protocol.cpp`) not pasted | Paste the controller's MAC, re-flash the HMI |
| Both MACs set, still nothing | Channel mismatch | Both must use `ESPNOW_WIFI_CHANNEL` (default 1) |
| Works at bench, fails in the field | ESP-NOW is same-channel-only; both boards on a network's other channel | Keep both off Wi-Fi or set the channel to match |

### 1.2 The pairing procedure (one-time)

1. Boot the controller → read `[ESP-NOW] Controller MAC: XX:…`.
2. Paste it into `CONTROLLER_PEER_MAC` in `src/MultiDryerHMI/serial_protocol.cpp`.
3. Boot the HMI → read its MAC.
4. Paste it into `HMI_PEER_MAC` in `src/MultiDryerController/espnow_link.h`, re-flash.

**Diagnose:** both serial monitors should show clean sends. The controller's
`hmiReachable` flag turns true when the HMI ACKs. Expect a `[STATUS]`/status
packet **every 1 s** once paired.

### 1.3 Status packets arrive but the HMI shows stale values

- **Cause:** the HMI's `applyStatusPacket` only updates on *valid* packets
  (type + checksum). A corrupted/truncated packet is dropped silently.
- **Fix:** check the shared `espnow_protocol.h` is **byte-identical** in both
  folders — if the copies drifted, struct sizes mismatch and every packet is
  rejected.

---

## 2. Sensor-Fail Vent Behavior (Safety)

This is **intended behavior**, not a bug: if the SHT31 temperature feedback is
lost, the heater can never run at full power.

| Observation | Meaning | Action |
|---|---|---|
| `FLAG_SHT31` clears on the HMI | SHT31 not reporting valid data | Check I2C wiring (SDA→21, SCL→22), pull-ups, address (0x44 / 0x45) |
| Heater + inlet fan off, **exhaust fan on** while in DRYING | Vent guard active — `pidCOMPUTE()` sees `!sht31OK` | Fix the sensor; the unit is intentionally venting instead of heating |
| `[STATUS]` shows `temp=0` or stale temp | Sensor read failing or hung bus | Re-seat the SHT31; power-cycle the controller |
| Serial shows CRC errors | Bad wiring / noise on I2C | Shorten leads, keep I2C wiring away from AC wiring |

> **Rule:** a dead sensor must never cause full-power heating. If you see the
> heater ON with no valid temperature, something is wrong with the vent-guard
> logic — report it.

---

## 3. Controller Won't Boot / Flashing Fails

| Symptom | Likely cause | Fix |
|---|---|---|
| Board stuck in download mode / boot loop | A strapping pin is loaded down (0, 2, 4, 5, 12, 15) | Check wiring on strapping pins; remove external pull-ups |
| SSR clicks / pulses at power-on | GPIO 14 used as an output (PWM burst at boot) | Move to a clean GPIO; never use GPIO 14 |
| Upload fails with peripherals attached | A pin on the flash (6–11) or UART0 (1/3) line is loaded | Free GPIO 1/3 for USB-serial; keep 6–11 untouched |
| Random resets during operation | Brown-out (5 V rail too weak) or WiFi current spikes | 12 V→5 V buck ≥ 3 A; add bulk capacitance on the 5 V rail |

**Diagnose:** open the serial monitor at 115200 — the boot banner order is
pins → SHT31 → load cell → PID → drying → ESP-NOW. Whichever line is missing/
crashing identifies the failing module.

---

## 4. Load Cell / Weight

| Symptom | Likely cause | Fix |
|---|---|---|
| `WARNING: HX711 not responding!` | Wiring / power / DOUT floating | Check DOUT=35, SCK=32, VCC, GND; HX711 must be powered before `is_ready()` |
| Weight reads 0.000 always | Sensor not ready → `readLoadCell()` returns 0 | Check wiring; watch for the transition-only "not ready" print |
| Weight is negative | Noise clamp or wrong factor sign | `readLoadCell()` clamps negatives to 0; re-calibrate |
| TARE/CALIBRATE "ignored" | **Session active** — commands gated to IDLE | Press STOP, then TARE/CALIBRATE |
| Water loss corrupt after reboot mid-drying | A TARE ran during the session (destroyed reference) | Shouldn't happen (gated); if it did, the firmware was older or NVS was cleared |
| Weight jumps with the heater on | AC noise coupling into the HX711 | Keep load cell leads twisted & away from AC; add 100 nF on HX711 VCC |

Full procedure: [`calibration-guide.md`](calibration-guide.md).

---

## 5. Session / NVS Persistence

| Symptom | Likely cause | Fix |
|---|---|---|
| Completed session "resurrects" as DRYING after reboot | NVS marker left non-IDLE (old firmware wrote `state` in config persist) | Press STOP after COMPLETE; on current firmware this can't happen |
| Setpoint/water-loss target reset after reboot | Config never persisted | Send `SET_TEMPERATURE` / `SET_WATER_LOSS` once — values persist from then on |
| Mid-session reboot loses up to 30 s of runtime | Periodic save cadence (`DRYER_SAVE_INTERVAL_MS` = 30 s) | Expected by design; nothing to fix |
| Restored session weight looks wrong | HX711 offset drifted between save and boot | The saved raw offset is re-applied on restore; if still off, verify the load cell mechanically |
| NVS corrupted / want a factory reset | Stale or bad saved state | Clear NVS: `Preferences` namespace `drying` (session/config) and `loadcell` (factor); erase flash in the IDE then re-flash |

---

## 6. HMI Display / Touch

| Symptom | Likely cause | Fix |
|---|---|---|
| Display stays black / splash only | Board config mismatch | `esp_panel_board_custom_conf.h` is **Waveshare ESP32-S3-Touch-LCD-7** specific — verify against your actual board, or display/touch init fails silently |
| Touch unresponsive but display works | GT911 config wrong for your panel | Check the touch I2C pins / reset in the board config |
| UI janky after a button press | Blocking `delay()` in an LVGL callback | Keep callbacks short (the dashboard quick-start uses small 50 ms gaps by design) |

---

## 7. PID / Temperature

| Symptom | Likely cause | Fix |
|---|---|---|
| Heater never comes on | Setpoint ≤ 0, or SHT31 lost (vent guard) | Send `SET_TEMPERATURE`; check `FLAG_SHT31` |
| Big overshoot / slow to reach setpoint | Tuning off for your chamber | Adjust KP/KD in `PID_CONFIG.h` (start KP 4.0 / KD 22.0); log `pidOutput` |
| Temperature oscillates | Sample time vs. sensor cadence mismatch | `pid.SetSampleTime` = `SHT31_READ_INTERVAL_MS` (2 s) — keep them matched |
| `FLAG_PID` set but outputs don't change | PID in AUTOMATIC but output 0 = venting | Normal when above setpoint — unit vents below target |

---

## 8. Collecting a Diagnostic Snapshot

Before reporting an issue, capture:

1. **Controller serial** (115200) — last 100 lines: boot banner, `[STATUS]` lines,
   `[ESP-NOW]` errors, `[DRYER]` transitions.
2. **HMI serial** — pairing prints, send failures.
3. **HMI dashboard state** — current `DSTATE`, flags, temp/humidity/weight.
4. **What changed** — new wiring, new firmware, mechanical change, power event.

**Status packet quick decode** (from the diagnostics screen or serial):
- `state`: 0 IDLE · 1 DRYING · 2 COMPLETE · 3 PAUSED
- `flags`: 0x01 heater · 0x02 fan · 0x04 exhaust · 0x08 PID · 0x10 SHT31
- `estimatedEDT = 0` → still estimating, not an error.

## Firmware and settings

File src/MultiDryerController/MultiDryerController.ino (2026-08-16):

// MultiDryerController.ino
// ESP32 38-pin controller.
// Hardware wiring: references/plans/hardware-wiring.md
// Pin map:         PINS_CONFIG.h
// Protocol:        espnow_protocol.h (shared with the HMI, keep byte-identical)

#include "PINS_CONFIG.h"
#include "SHT31_CONFIG.h"
#include "LOADCELL_CONFIG.h"
#include "PID_CONFIG.h"
#include "DRYER_STATE.h"
#include "espnow_protocol.h"
#include "espnow_link.h"

// ── Shared SHT31 state (consumed by SHT31_CONFIG.h) ──────────────────────────
bool   sht31OK             = false;
float  CURRENT_HUMIDITY    = 0.0f;
double CURRENT_TEMPERATURE = 0.0;

// ── PID state (consumed by PID_CONFIG.h) ─────────────────────────────────────
// Default 0.0 = heater stays off until the HMI sends a target temperature.
double TEMPERATURE_SETPOINT = 0.0;
double PID_OUTPUT           = 0.0;

unsigned long _lastStatusPrint = 0;

const char* stateName(uint8_t s) {
  switch (s) {
    case DSTATE_IDLE:     return "IDLE";
    case DSTATE_DRYING:   return "DRYING";
    case DSTATE_PAUSED:   return "PAUSED";
    case DSTATE_COMPLETE: return "COMPLETE";
    default:              return "?";
  }
}

// ── SSR driver (declared extern in PID_CONFIG.h) ─────────────────────────────
// SSR1 = PTC heater, SSR3 = inlet fan, SSR4 = exhaust fan (3-SSR build)
//
// ssrStateFlags mirrors the REAL output state (used by the ESP-NOW status
// packet so the HMI always shows what is actually energized — PID-driven or
// manual override). Bit layout matches FLAG_HEATER / FLAG_FAN / FLAG_EXHAUST
// from espnow_protocol.h.
uint8_t ssrStateFlags = 0;

void operateSSR(int relayIndex, bool state) {
    int pin;
    uint8_t flag;
    switch (relayIndex) {
        case 1: pin = SSR1_PIN; flag = FLAG_HEATER; break;
        case 3: pin = SSR3_PIN; flag = FLAG_FAN; break;
        case 4: pin = SSR4_PIN; flag = FLAG_EXHAUST; break;
        default: return;
    }
    digitalWrite(pin, state ? HIGH : LOW);
    if (state) ssrStateFlags |= flag;
    else       ssrStateFlags &= (uint8_t)~flag;
}

void setup() {
  Serial.begin(115200);
  delay(200);

  // Fail-safe: force all SSR outputs OFF before anything else — SSR inputs
  // float (high-Z) during the ~1 s boot window, so pins are driven LOW as
  // the first step of setup(), before WiFi/ESP-NOW init.
  pinMode(SSR1_PIN, OUTPUT); digitalWrite(SSR1_PIN, LOW);
  pinMode(SSR3_PIN, OUTPUT); digitalWrite(SSR3_PIN, LOW);
  pinMode(SSR4_PIN, OUTPUT); digitalWrite(SSR4_PIN, LOW);

  initLoadCell();   // HX711 weight sensor (DOUT=35, SCK=32)
  initSHT31();      // temperature/humidity (I2C 21/22)
  initPID();        // PTC heater temperature control (starts in MANUAL = off)
  initDrying();     // drying state machine (IDLE)
  initEspNow();     // wireless link to the HMI board
}

void loop() {
  // Non-blocking SHT31 read state machine — call every iteration
  updateSHT31();

  // PID: compute + drive SSRs (PID_v1 throttles itself to its 1 s sample time)
  pidCOMPUTE();

  // Drying state machine: 1 Hz tick (weight cache, water loss, auto-complete)
  updateDrying();

  // ESP-NOW: process HMI commands + send periodic status packets (1 Hz)
  espnowUpdate();

  // Debug print every 5 s — mirrors what the HMI receives over ESP-NOW
  unsigned long now = millis();
  if (now - _lastStatusPrint >= 5000) {
    _lastStatusPrint = now;
    Serial.printf("[STATUS] %-8s temp=%.2f C  hum=%.1f %%  weight=%.3f kg  "
                  "loss=%.1f%%  setpoint=%.1f C  pid=%.0f  hmi=%s\n",
                  stateName(getDryerState()),
                  (float)CURRENT_TEMPERATURE,
                  CURRENT_HUMIDITY,
                  getWeightKg(),
                  getWaterLoss(),
                  TEMPERATURE_SETPOINT,
                  PID_OUTPUT,
                  hmiReachable ? "reachable" : "not seen");
  }
}

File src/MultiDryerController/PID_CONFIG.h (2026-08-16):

// PID_CONFIG.h
// Multi Dryer Controller — PID temperature control for the PTC heater,
// using SHT31 temperature feedback.
//
// Adapted from references/loadcell/FishDryer/PID_CONFIG.h:
//   - Same PID_v1 library and PD tuning style (KP/KI/KD).
//   - Same output model: 0..5000, output > 0 → heat, else vent.
//   - SSR mapping adapted to the Multi Dryer loads (3-SSR build):
//       heating: SSR1 (PTC heater) + SSR3 (inlet fan)  ON
//       venting: SSR1 + SSR3 OFF, SSR4 (exhaust fan) ON
//   - NEW safety guard (not in the baseline): if the SHT31 feedback is
//     unavailable, the heater is forced OFF and the unit vents instead —
//     a dead sensor must never cause full-power heating.
//
// Requires the Arduino PID library (br3ttb/PID_v1).

#ifndef PID_CONFIG_H
#define PID_CONFIG_H

#include <PID_v1.h>
#include "PINS_CONFIG.h"
#include "SHT31_CONFIG.h"

// ── Tuning parameters (starting point — tune on the real rig) ─────────────────
#define PID_KP  4.0
#define PID_KI  0.0
#define PID_KD  22.0

// Externals defined in MultiDryerController.ino
extern double TEMPERATURE_SETPOINT;
extern double PID_OUTPUT;

// PID_v1 wants double in/out/setpoint — CURRENT_TEMPERATURE is already double
PID pid(&CURRENT_TEMPERATURE, &PID_OUTPUT, &TEMPERATURE_SETPOINT, PID_KP, PID_KI, PID_KD, DIRECT);

// SSR driver implemented in MultiDryerController.ino
extern void operateSSR(int relayIndex, bool state);

// ── Init (call once in setup()) ───────────────────────────────────────────────
void initPID() {
    pid.SetOutputLimits(0, 5000);
    pid.SetSampleTime(SHT31_READ_INTERVAL_MS);   // match sensor refresh rate (2 s)
    pid.SetMode(MANUAL);                         // stay off until the HMI sends PID_START / START_DRYING
    PID_OUTPUT = 0;
}

// ── Control ───────────────────────────────────────────────────────────────────
void setPIDSetpoint(double setpoint) {
    TEMPERATURE_SETPOINT = setpoint;
    Serial.printf("[PID] setpoint %.1f C\n", setpoint);
}

void startPID() {
    pid.SetMode(AUTOMATIC);
    Serial.printf("[PID] started (setpoint %.1f C)\n", TEMPERATURE_SETPOINT);
}

void stopPID() {
    pid.SetMode(MANUAL);
    PID_OUTPUT = 0;
    operateSSR(1, false);
    operateSSR(3, false);
    operateSSR(4, false);
    Serial.println(F("[PID] stopped — all outputs OFF"));
}

// ── Compute + drive SSRs (call every loop(); PID_v1 throttles to sample time) ─
void pidCOMPUTE() {
    // Stopped (MANUAL) means truly all-off — never touch SSRs here, so
    // stopPID()'s all-off promise holds and manual HEATER_ON overrides survive.
    if (pid.GetMode() == MANUAL) return;

    // Safety guard: never heat without valid temperature feedback — vent instead.
    if (!sht31OK) {
        PID_OUTPUT = 0;         // keep status flags consistent with real SSR state
        operateSSR(1, false);   // heater OFF
        operateSSR(3, false);   // inlet fan OFF
        operateSSR(4, true);    // exhaust fan ON — vent instead of heating
        return;
    }

    pid.Compute();

    if (PID_OUTPUT > 0) {
        // Heating: PTC + inlet fan circulate air
        operateSSR(1, true);
        operateSSR(3, true);
        operateSSR(4, false);
    } else {
        // Venting: heater/inlet off, exhaust fan on
        operateSSR(1, false);
        operateSSR(3, false);
        operateSSR(4, true);
    }
}

#endif // PID_CONFIG_H

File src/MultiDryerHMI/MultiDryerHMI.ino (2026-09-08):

#include <Arduino.h>
#include <esp_display_panel.hpp>
#include <lvgl.h>
#include "lvgl_v8_port.h"

#include "dryer_data.h"
#include "drying_presets.h"
#include "ui_theme.h"
#include "ui_styles.h"
#include "serial_protocol.h"
#include "screen_manager.h"
#include "alert_popup.h"

using namespace esp_panel::drivers;
using namespace esp_panel::board;

// Global dryer data instance
DryerData dryerData;

// LVGL timer for periodic UI updates
static void uiUpdateTimerCb(lv_timer_t* timer) {
    (void)timer;
    updateCurrentScreen();
    checkAlerts();
}

void setup() {
    Serial.begin(115200);
    Serial.println("=== Multi Dryer HMI ===");

    // Initialize dryer data with defaults
    initDryerData();

    // Initialize display board
    Serial.println("[HMI] Initializing display board...");
    Board *board = new Board();
    board->init();

#if LVGL_PORT_AVOID_TEARING_MODE
    auto lcd = board->getLCD();
    lcd->configFrameBufferNumber(LVGL_PORT_DISP_BUFFER_NUM);
#if ESP_PANEL_DRIVERS_BUS_ENABLE_RGB && CONFIG_IDF_TARGET_ESP32S3
    auto lcd_bus = lcd->getBus();
    if (lcd_bus->getBasicAttributes().type == ESP_PANEL_BUS_TYPE_RGB) {
        static_cast<BusRGB *>(lcd_bus)->configRGB_BounceBufferSize(lcd->getFrameWidth() * 10);
    }
#endif
#endif
    assert(board->begin());

    // Initialize LVGL
    Serial.println("[HMI] Initializing LVGL...");
    lvgl_port_init(board->getLCD(), board->getTouch());

    // Initialize UART communication with dryer controller
    Serial.println("[HMI] Initializing serial protocol...");
    serialProtoInit();

    // Load saved drying presets (seeds Tuyo/Danggit/Pusit on first boot)
    // NOTE: Must run AFTER board->begin() so the LCD frame buffers are allocated
    // first. presetsInit() uses NVS (flash) and some heap for Preferences; running
    // it before board init consumed heap needed by the RGB panel driver.
    presetsInit();

    // Build the UI (must hold LVGL mutex)
    Serial.println("[HMI] Building UI...");
    lvgl_port_lock(-1);

    // Initialize styles and theme
    initStyles();

    // Initialize alert system
    alertInit();

    // Initialize screen manager (creates and shows boot screen)
    screenManagerInit();

    // Create periodic timer for UI data updates (every 2 seconds)
    lv_timer_create(uiUpdateTimerCb, CHART_UPDATE_MS, NULL);

    lvgl_port_unlock();

    Serial.println("[HMI] Initialization complete!");
    Serial.printf("[HMI] Free heap: %lu KB\n", (unsigned long)(ESP.getFreeHeap() / 1024));
}

void loop() {
    // Handle UART communication with dryer controller (non-blocking)
    serialProtoUpdate();

    delay(10);
}

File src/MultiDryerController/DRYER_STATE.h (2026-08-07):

// DRYER_STATE.h
// Multi Dryer Controller — drying state machine + water-loss tracking.
//
// States (DSTATE_* from espnow_protocol.h — shared with the HMI):
//       IDLE ──START──► DRYING ──auto (target reached)──► COMPLETE
//        ▲              │  ▲
//        │ STOP         ▼  │ RESUME
//                     PAUSED
//
// Water loss % = (initialWeight − currentWeight) / initialWeight × 100.
// When waterLossTarget > 0 and waterLoss reaches it, the cycle auto-completes
// (heater/fans off). Target 0.0 = auto-complete disabled (STOP_DRYING ends it).
//
// All weight reads flow through this module (1 Hz cache) so the ESP-NOW status
// packet and the water-loss math always use the same value.

#ifndef DRYER_STATE_H
#define DRYER_STATE_H

#include <Preferences.h>
#include "espnow_protocol.h"
#include "LOADCELL_CONFIG.h"
#include "PID_CONFIG.h"

#define DRYER_TICK_MS  1000

// ── Session persistence (NVS) ────────────────────────────────────────────────
// Lets a drying session survive a controller reboot / watchdog reset:
//   - initial weight AND the HX711 raw offset (the zero reference) are saved,
//     so weight/water-loss keep meaning even after a full power cycle, where
//     the HX711 offset drifts. On restore the offset is re-applied (no re-tare).
//   - elapsed runtime, water-loss target and temperature setpoint are restored.
//   - An active session (DRYING/PAUSED) resumes automatically on boot;
//     DRYING re-enables the PID. TARE/CALIBRATE are blocked while a session is
//     active (see espnow_link.h) so the HMI's boot-time TARE cannot destroy the
//     restored zero reference.
#define DRYER_PREFS_NS          "drying"
#define DRYER_PREFS_MAGIC       0xD1
#define DRYER_SAVE_INTERVAL_MS  30000   // periodic save cadence while drying

// ── Tracking state (single writer: updateDrying(), loop context) ─────────────
static uint8_t       _state           = DSTATE_IDLE;
static float         _waterLossPct    = 0.0f;
static float         _waterLossTarget = 0.0f;   // 0 = auto-complete disabled
static float         _weightKg        = 0.0f;   // cached, refreshed at 1 Hz
static float         _initialWeightKg = 0.0f;
static unsigned long _runMs           = 0;      // drying time, pauses excluded
static unsigned long _lastTickMs      = 0;
static unsigned long _lastSaveMs      = 0;      // periodic session-save throttle
static uint32_t      _runtimeSeconds  = 0;
static uint32_t      _estimatedEDT    = 0;      // seconds; 0 = unknown

// ── Getters (used by the ESP-NOW status packet) ──────────────────────────────
uint8_t  getDryerState()      { return _state; }
float    getWaterLoss()       { return _waterLossPct; }
float    getWaterLossTarget() { return _waterLossTarget; }
float    getWeightKg()        { return _weightKg; }
uint32_t getRuntimeSeconds()  { return _runtimeSeconds; }
uint32_t getEstimatedEDT()    { return _estimatedEDT; }

// Forward declarations — persistence functions are defined at the bottom
static void saveDryingSession(uint8_t state);
static void clearDryingSession();
static void persistDryerConfig();
static void restoreDryingSession();

// ── Control ───────────────────────────────────────────────────────────────────
void setWaterLossTarget(float pct) {
    _waterLossTarget = constrain(pct, 0.0f, 100.0f);
    Serial.printf("[DRYER] water-loss target %.1f %%\n", _waterLossTarget);
}

void initDrying() {
    _state = DSTATE_IDLE;
    _waterLossPct = 0.0f; _waterLossTarget = 0.0f;
    _weightKg = 0.0f; _initialWeightKg = 0.0f;
    _runMs = 0; _runtimeSeconds = 0; _estimatedEDT = 0;
    _lastTickMs = millis();
    _lastSaveMs = millis();
    restoreDryingSession();   // auto-resume an interrupted session, if any
}

// Fresh session: capture initial weight, start PID, begin tracking
void startDrying() {
    if (_state == DSTATE_DRYING) {
        Serial.println(F("[DRYER] already drying"));
        return;
    }
    if (_state != DSTATE_IDLE) {
        Serial.println(F("[DRYER] starting fresh session (restart)"));
    }
    _initialWeightKg = readLoadCell();
    _weightKg        = _initialWeightKg;
    _runMs = 0; _runtimeSeconds = 0; _estimatedEDT = 0; _waterLossPct = 0;
    _lastTickMs = millis();
    _lastSaveMs = millis();
    _state = DSTATE_DRYING;
    if (TEMPERATURE_SETPOINT <= 0.0) {
        Serial.println(F("[DRYER] WARNING: no setpoint set — send SET_TEMPERATURE"));
    }
    startPID();
    saveDryingSession(DSTATE_DRYING);
    Serial.printf("[DRYER] started. Initial weight %.3f kg\n", _initialWeightKg);
}

void stopDrying() {
    stopPID();   // all SSRs off
    _state = DSTATE_IDLE;
    _runMs = 0; _runtimeSeconds = 0; _estimatedEDT = 0;
    _waterLossPct = 0; _initialWeightKg = 0;
    clearDryingSession();   // session over — nothing to resume later
    Serial.println(F("[DRYER] stopped"));
}

void pauseDrying() {
    if (_state != DSTATE_DRYING) return;
    stopPID();   // all SSRs off
    _state = DSTATE_PAUSED;
    saveDryingSession(DSTATE_PAUSED);
    Serial.println(F("[DRYER] paused (session saved)"));
}

void resumeDrying() {
    if (_state != DSTATE_PAUSED) return;
    _state = DSTATE_DRYING;
    startPID();
    saveDryingSession(DSTATE_DRYING);
    Serial.println(F("[DRYER] resumed (session saved)"));
}
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

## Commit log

2026-08-07 Add ESP32 controller base: pin config and SHT31 sensor driver
2026-08-07 Add ESP-NOW HMI link, load cell driver and PID temperature control
2026-08-07 Add NVS session persistence (resume drying after reboot)
    [DRYER_STATE.h]
2026-08-07 Add Pause/Resume buttons to HMI control screen
2026-08-07 Add wiring diagram link to README and docs/schematic
2026-08-07 Add MIT license and expand .gitignore for Arduino/PlatformIO build artifacts
2026-08-07 Add project docs: protocol API, tech stack, wiring plan, bring-up checklist, calibration guide
2026-08-07 Add system architecture doc with block diagram and flow charts
2026-08-14 Finish HMI feature set: preset management, HOW TO USE screen, rebrand, and UI previews
    Add user-managed drying presets (name/temp/water-loss target, add/delete,
    persisted in HMI NVS), wire the previously orphaned HOW TO USE screen into
    dashboard navigation, rebrand from SolAraw to Multi-Purpose Dryer (removing
    the broken solaraw logo that would not compile), and fix invalid \xB0C
    escapes plus a non-existent LVGL symbol. Add a headless screenshot renderer
    (sim/screenshot) that compiles the real screens against LVGL 8.3 and outputs
    validated 800x480 PNG previews to docs/ui/, and include the HMI user guide,
    safety/thermal design, and Cirkit schematic assets.
    Generated with Codebuff 🤖
    Co-Aut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
    [MultiDryerHMI.ino, analytics_screen.cpp]
2026-08-14 Remove sim/ screenshot tool from the repo
    Drop the local-only LVGL screenshot renderer from version control (files
    stay on disk, sim/ added to .gitignore) and point the README at the
    docs/ui/ previews instead.
    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
2026-08-14 Remove resistors from schematic wiring doc
    Drop all resistor components (SSR series/pull-down/base resistors,
    I2C pull-ups, HX711 voltage divider, RC snubbers) from the wiring
    guide. SSR fail-safe is now firmware-enforced (pins forced LOW at
    the top of setup) instead of relying on external pull-downs, and
    the HX711 runs at 3V3 with direct logic levels.
    🤖 Generated with Codebuff
2026-08-14 Remove resistor references from guides, README, and firmware docs
    The design no longer uses external resistors (SSR pull-downs, I2C
    pull-ups, HX711 divider, snubbers). Update safety-and-thermal,
    bring-up checklist, troubleshooting, tech stack, system
    architecture, block diagram, README, and firmware comments so the
    fail-safe is consistently described as firmware-enforced (SSR pins
    forced LOW at the top of setup()) instead of hardware pull-downs.
    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
    [MultiDryerController.ino, PINS_CONFIG.h]
2026-08-14 Fix remaining stale references across docs and firmware
    HMI user guide now reflects that manual relay control is wired on
    the Control screen, the sensor-test comment no longer says "on
    Nano", and the diagnostics screen reports NVS instead of EEPROM.
    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
    [diagnostics_screen.cpp]
2026-08-14 Add BOM and test plan docs, completing the docs roadmap
    BOM guide expands the wiring-plan draft into a full ordering list
    with specs, quantities, and sourcing notes (explicitly excluding
    resistors and level shifters per the current design). Test plan
    specifies host unit tests for the protocol, state machine, and
    command handler, plus HMI screen checks and regression rules.
    Marks both docs complete in the roadmap.
    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
2026-08-16 Update BOM and align docs/firmware to the 3-SSR build
    Adopt the actual build parts (3× SSR-40DA 40 A, PTC heater 1500 W, 4×50 kg
    load cells on one HX711, 220V→12V PSU + 12V→5V buck, fuses 10/2/2 A, no
    separate exhaust outlet) across the BOM, wiring/safety/diagram docs, and the
    controller firmware (drop the dead SSR2/GPIO 25 channel).
    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
2026-09-08 Add Fritzing schematic PNG and source
    [multidryer.fzz]
2026-09-08 Update schematic PNG export
2026-09-08 Update Fritzing schematic source
    [multidryer.fzz]
2026-09-08 Document Fritzing schematic as primary, demote Cirkit to legacy
2026-10-22 Fix ESP-Now on core 3.x, SHT31 reading, and HMI layout issues
    Controller:
    - espnow: accept esp_now_recv_info_t* callback (ESP32 core 3.x), read MAC
    via esp_wifi_get_mac()/esp_read_mac(), guard unset peer MAC
    - SHT31: use Adafruit_SHT31 (proven FishDryer path), auto-detect 0x44/0x45,
    I2C bus scan diagnostics, re-probe after repeated read failures
    - status line now reports the active sensor address (sht=0x44 / MISSING)
    HMI:
    - match ESP-Now recv callback signature, robust MAC print with retries and
    an early factory-MAC banner so pairings are always visible
    - diagnostics: drop power readings and version/display info, move
    RUN SENSOR TEST under the SHT31 row
    - analytics: lay out value he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
2026-10-22 Update docs for SHT31, ESP-NOW pairing, HMI presets, and pin map
    - Pin map: document SSR1/SSR3/SSR4 on GPIO 25/26/27 (GPIO 13 now spare)
    and fix the stale PINS_CONFIG.h comments/spare list
    - SHT31: Adafruit_SHT31 driver, 2 s poll, 0x44/0x45 auto-detect, I2C scan
    and re-probe after 3 failures, sht= status field
    - ESP-NOW: document core 3.x receive callback, MAC read fallbacks, exact
    pairing log lines, and the zero-MAC guard
    - HMI: preset manager keyboard behavior, dynamic NVS presets, diagnostics
    cards (power/version rows removed), analytics layout
    - Build: note the >=3 MB HMI app partition and Adafruit_SHT31 dependency
2026-10-28 Switch load cell driver to HX711_ADC (DOUT 33) and add serial bench commands
    - Replace HX711 API with Olav Kallhovd's HX711_ADC (polled from loop).
    - Move HX711 DOUT to GPIO 33 (SCK stays 32), matching the proven bench wiring.
    - Persist calibration under loadcell/factor_v2; ignore old-library factors.
    - Save/restore session zero offset via getTareOffset/setTareOffset; bump session magic to 0xD2.
    - Add HELP/TARE/CALIBRATE/READ/STATUS/FACTOR/RESET_CAL/STREAM/INTERVAL serial commands.
    - Initialize ESP-NOW before load-cell settling so the HMI boot TARE is queued.
    - Update calibration, wiring, architecture, and library documentation.
2026-11-01 Auto-tare on boot when idle and expose load-cell raw diagnostics
    The HMI only sends TARE once, three seconds after its own boot. A controller-only reboot (e.g. after flashing) therefore left tareOffset at 0, making HX711_ADC compute a huge negative weight that was clamped to 0.0 kg on the HMI.
    - Auto-tare after session restore only when the dryer state is IDLE.
    - Keep the saved zero reference (and ignore boot TARE) when a session is restored.
    - Print tare offset, raw counts, raw weight, and clamped weight in STATUS.
    - Print the resulting offset after TARE.
    - Document the new boot behavior in the calibration guide.

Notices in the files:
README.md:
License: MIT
